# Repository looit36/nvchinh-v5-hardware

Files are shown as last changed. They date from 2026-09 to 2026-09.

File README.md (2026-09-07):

# MiniChinh - Micromouse Robot Controller Board

Dự án thiết kế mạch điều khiển robot dò mê cung (Micromouse) sử dụng phần mềm **KiCad**. Mạch tích hợp vi điều khiển STM32F411 tốc độ cao, driver động cơ kép, cảm biến quán tính IMU 6 trục, cảm biến encoder từ tính và dàn cảm biến quang hồng ngoại (IR).

---

## Hình ảnh Mạch PCB (3D & 2D Layout)

### Phối cảnh 3D
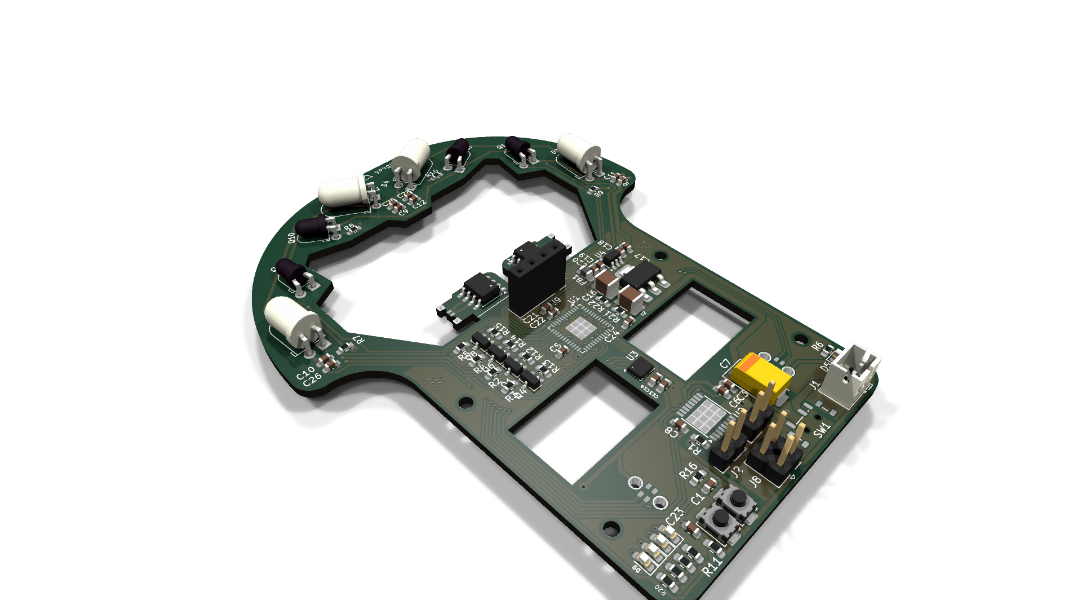
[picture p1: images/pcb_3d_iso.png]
PCB 3D Isometric


| Mặt trên | Mặt dưới |
| :---: | :---: |
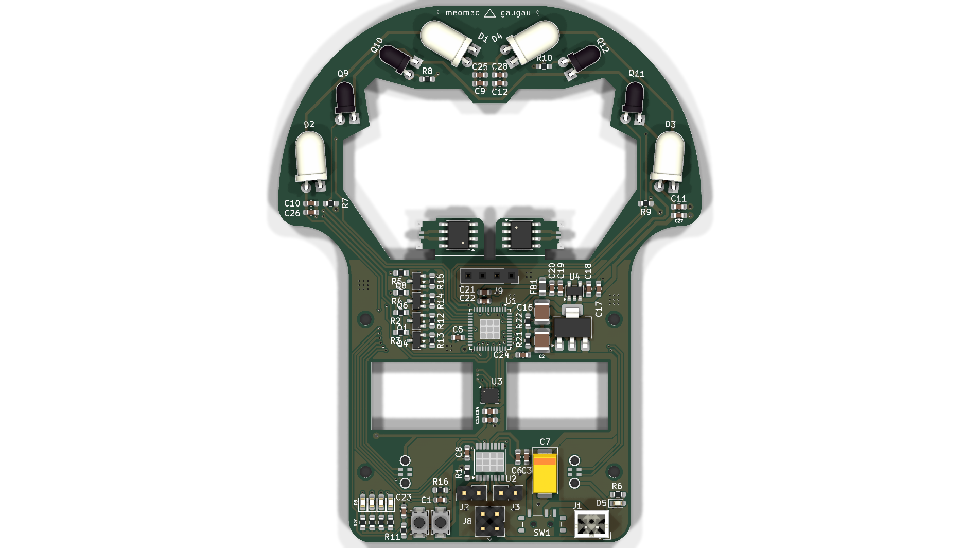
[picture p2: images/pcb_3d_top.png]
PCB Top 3D
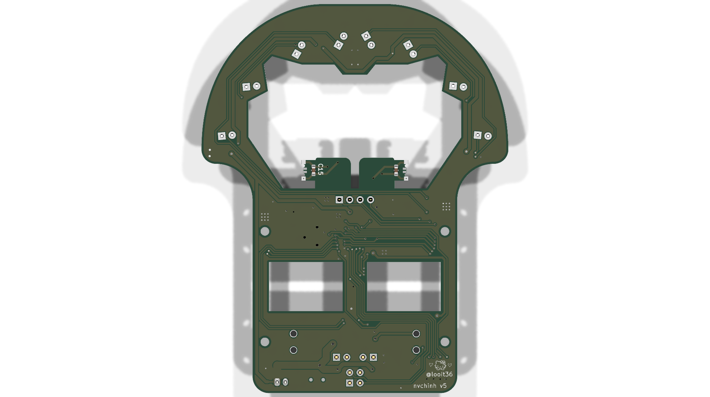
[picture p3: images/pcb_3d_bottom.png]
PCB Bottom 3D
|  |  |

| F.Cu + Silk | B.Cu + Silk |
| :---: | :---: |
| Layout Mặt trước (F.Cu + Silk) | Layout Mặt sau (B.Cu + Silk) |

---

## Sơ đồ Nguyên lý

### 1. Sơ đồ khối chính
Main Schematic

### 2. Sơ đồ mạch phát & thu hồng ngoại
IR Emitter Schematic

---

## Thông số Kỹ thuật Phần cứng

| Thành phần | Chi tiết linh kiện | Chức năng |
| :--- | :--- | :--- |
| **Vi điều khiển (MCU)** | STM32F411CEU6 (UFQFPN-48) | ARM Cortex-M4 100MHz, 512KB Flash, 128KB SRAM |
| **Driver Động cơ** | TI DRV8833PW (HTSSOP-16) | Điều khiển 2 động cơ DC độc lập, dòng tối đa 1.5A/kênh |
| **Cảm biến góc (IMU)** | Bosch BMI160 (LGA-14) | Cảm biến gia tốc & con quay hồi chuyển 6 trục (SPI/I2C) |
| **Bộ mã hóa bánh xe (Encoder)** | 2x MT6701CT (SO-8) | Cảm biến góc từ tính độ chính xác cao cho 2 bánh xe |
| **Cảm biến khoảng cách / Mê cung** | 4x SFH4546 (IR LED) + 4x SFH300 (Phototransistor) | Đo khoảng cách các vách tường mê cung, lái bằng MOSFET AO3400A |
| **Mạch nguồn (Power)** | AMS1117-5.0 & TI TPS73633DBV | Ổn áp 5V và 3.3V Low-Dropout cấp nguồn ổn định cho MCU và cảm biến |
| **Giao tiếp lập trình** | Cổng SWD chuẩn (GND, 3V3, SWDIO, SWCLK) | Nạp và gỡ lỗi bằng ST-Link / J-Link |
| **Ngoại vi & UI** | 5x LED báo trạng thái SMD 0603, 2x nút nhấn, 1x công tắc nguồn MSK12C02 | Giao diện tương tác và chọn chế độ chạy |

---

## Cấu trúc Thư mục

```text
minichinh/
├── minichinh.kicad_pro       # File dự án KiCad chính
├── minichinh.kicad_sch       # Sơ đồ nguyên lý chính
├── iremitter.kicad_sch       # Sơ đồ nguyên lý khối IR Emitter
├── minichinh.kicad_pcb       # Bản vẽ thiết kế mạch in PCB
├── fp-lib-table              # Bảng thư viện footprint
├── mouse.pretty/             # Thư viện footprint tùy chỉnh cho robot
├── minichinh.csv             # Danh sách bảng linh kiện (BOM)
├── geber/                    # Bộ file Gerber sẵn sàng để đặt mạch gia công
├── images/                   # Hình ảnh sơ đồ schematic và render 3D / 2D PCB
│   ├── minichinh.svg
│   ├── minichinh_ir_emitter.svg
│   ├── minichinh_schematic.pdf
│   ├── pcb_3d_top.png
│   ├── pcb_3d_bottom.png
│   ├── pcb_3d_iso.png
│   ├── pcb_top_layout.svg
│   └── pcb_bottom_layout.svg
└── README.md                 # Tài liệu giới thiệu dự án
```

---

## Hướng dẫn Sử dụng

1. **Mở dự án:**
   - Cài đặt KiCad phiên bản 8.0 hoặc 9.0 trở lên.
   - Mở file `minichinh.kicad_pro` để truy cập sơ đồ nguyên lý và layout PCB.
2. **Gia công mạch (PCB Manufacturing):**
   - Bộ file Gerber nén và đầy đủ các lớp đã được tạo sẵn trong thư mục [`geber/`](geber/). Có thể gửi trực tiếp cho các nhà sản xuất PCB (JLCPCB, PCBWay, v.v.).

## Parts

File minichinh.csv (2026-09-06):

Reference | Qty | Value | DNP | Exclude from BOM | Exclude from Board | Footprint | Datasheet
C1,C21,C22,C23 | 4 | 0.1u |  |  |  | Capacitor_SMD:C_0603_1608Metric | ~
C2,C16 | 2 | 100u |  |  |  | Capacitor_SMD:C_1210_3225Metric_Pad1.33x2.70mm_HandSolder | ~
C3,C4,C13,C14,C15,C17,C18,C20,C24,C25,C26,C27,C28 | 13 | 0.1u |  |  |  | Capacitor_SMD:C_0603_1608Metric_Pad1.08x0.95mm_HandSolder | ~
C5 | 1 | 10u |  |  |  | Capacitor_SMD:C_0603_1608Metric | ~
C6 | 1 | 0.01u |  |  |  | Capacitor_SMD:C_0603_1608Metric_Pad1.08x0.95mm_HandSolder | ~
C7 | 1 | 220u |  |  |  | Capacitor_Tantalum_SMD:CP_EIA-7343-31_Kemet-D_HandSolder | ~
C8 | 1 | 2.2u |  |  |  | Capacitor_SMD:C_0603_1608Metric_Pad1.08x0.95mm_HandSolder | ~
C9,C10,C11,C12 | 4 | 4.7u |  |  |  | Capacitor_SMD:C_0603_1608Metric_Pad1.08x0.95mm_HandSolder | ~
C19 | 1 | 10u |  |  |  | Capacitor_SMD:C_0603_1608Metric_Pad1.08x0.95mm_HandSolder | ~
D1,D2,D3,D4 | 4 | SFH4546 |  | Excluded from BOM |  | LED_THT:LED_D5.0mm_Horizontal_O1.27mm_Z3.0mm_Clear | http://www.osram-os.com/Graphics/XPic1/00101982_0.pdf
D5,D6,D7,D8,D9 | 5 | LED |  |  |  | LED_SMD:LED_0603_1608Metric_Pad1.05x0.95mm_HandSolder | ~
FB1 | 1 | FerriteBead |  |  |  | Inductor_SMD:L_0805_2012Metric_Pad1.05x1.20mm_HandSolder | ~
J1 | 1 | Conn_01x02 |  | Excluded from BOM |  | Connector_JST:JST_PH_B2B-PH-K_1x02_P2.00mm_Vertical | ~
J2,J3 | 2 | Conn_01x02 |  | Excluded from BOM |  | Connector_PinHeader_2.54mm:PinHeader_1x02_P2.54mm_Vertical | ~
J4,J7 | 2 | Conn_01x06_Socket |  | Excluded from BOM |  | mouse:STAND_HOST_06 | ~
J5,J6 | 2 | Conn_01x06_Pin |  | Excluded from BOM |  | mouse:STAND_SLAVE_06 | ~
J8 | 1 | Conn_01x04_Pin |  | Excluded from BOM |  | Connector_PinHeader_2.54mm:PinHeader_2x02_P2.54mm_Vertical | ~
J9 | 1 | Conn_01x04_Pin |  | Excluded from BOM |  | Connector_PinSocket_2.54mm:PinSocket_1x04_P2.54mm_Vertical | ~
NT1 | 1 | NetTie_2 |  | Excluded from BOM |  | NetTie:NetTie-2_SMD_Pad0.5mm | ~
NT2 | 1 | NetTie_2 |  | Excluded from BOM |  | NetTie:NetTie-2_SMD_Pad2.0mm | ~
Q1,Q4,Q6,Q8 | 4 | AO3400A |  | Excluded from BOM |  | Package_TO_SOT_SMD:SOT-23 | http://www.aosmd.com/pdfs/datasheet/AO3400A.pdf
Q9,Q10,Q11,Q12 | 4 | SFH300 |  | Excluded from BOM |  | LED_THT:LED_D3.0mm_Horizontal_O1.27mm_Z2.0mm_IRBlack | http://www.osram-os.com/Graphics/XPic2/00101785_0.pdf
R1,R11,R12,R13,R14,R15,R21,R22 | 8 | 47k |  |  |  | Resistor_SMD:R_0603_1608Metric_Pad0.98x0.95mm_HandSolder | ~
R2,R3,R4,R5 | 4 | 10 |  |  |  | Resistor_SMD:R_0603_1608Metric_Pad0.98x0.95mm_HandSolder | ~
R6,R7,R8,R9,R10,R17,R18,R19,R20 | 9 | 1k |  |  |  | Resistor_SMD:R_0603_1608Metric_Pad0.98x0.95mm_HandSolder | ~
R16 | 1 | 10k |  |  |  | Resistor_SMD:R_0603_1608Metric_Pad0.98x0.95mm_HandSolder | ~
SW1 | 1 | SW_DPDT_x2 |  |  |  | Button_Switch_SMD:SW_SPDT_Shouhan_MSK12C02 | ~
SW2,SW3 | 2 | SW_Push |  |  |  | Button_Switch_SMD:SW_SPST_TS-1088-xR025 | ~
U1 | 1 | STM32F411CEUx |  | Excluded from BOM |  | Package_DFN_QFN:QFN-48-1EP_7x7mm_P0.5mm_EP3.5x3.5mm | https://www.st.com/resource/en/datasheet/stm32f411ce.pdf
U2 | 1 | DRV8833PW |  |  |  | Package_SO:HTSSOP-16-1EP_4.4x5mm_P0.65mm_EP3.4x5mm | http://www.ti.com/lit/ds/symlink/drv8833.pdf
U3 | 1 | BMI160 |  | Excluded from BOM |  | Package_LGA:Bosch_LGA-14_3x2.5mm_P0.5mm | https://www.bosch-sensortec.com/media/boschsensortec/downloads/datasheets/bst-bmi160-ds000.pdf
U4 | 1 | TPS73633DBV |  |  |  | Package_TO_SOT_SMD:SOT-23-5 | http://www.ti.com/lit/ds/symlink/tps736.pdf
U5 | 1 | AMS1117-5.0 |  |  |  | Package_TO_SOT_SMD:SOT-223-3_TabPin2 | http://www.advanced-monolithic.com/pdf/ds1117.pdf
U6,U7 | 2 | MT6701CT |  | Excluded from BOM |  | Package_SO:SO-8_3.9x4.9mm_P1.27mm | https://www.magntek.com.cn/upload/MT6701_Rev.1.5.pdf

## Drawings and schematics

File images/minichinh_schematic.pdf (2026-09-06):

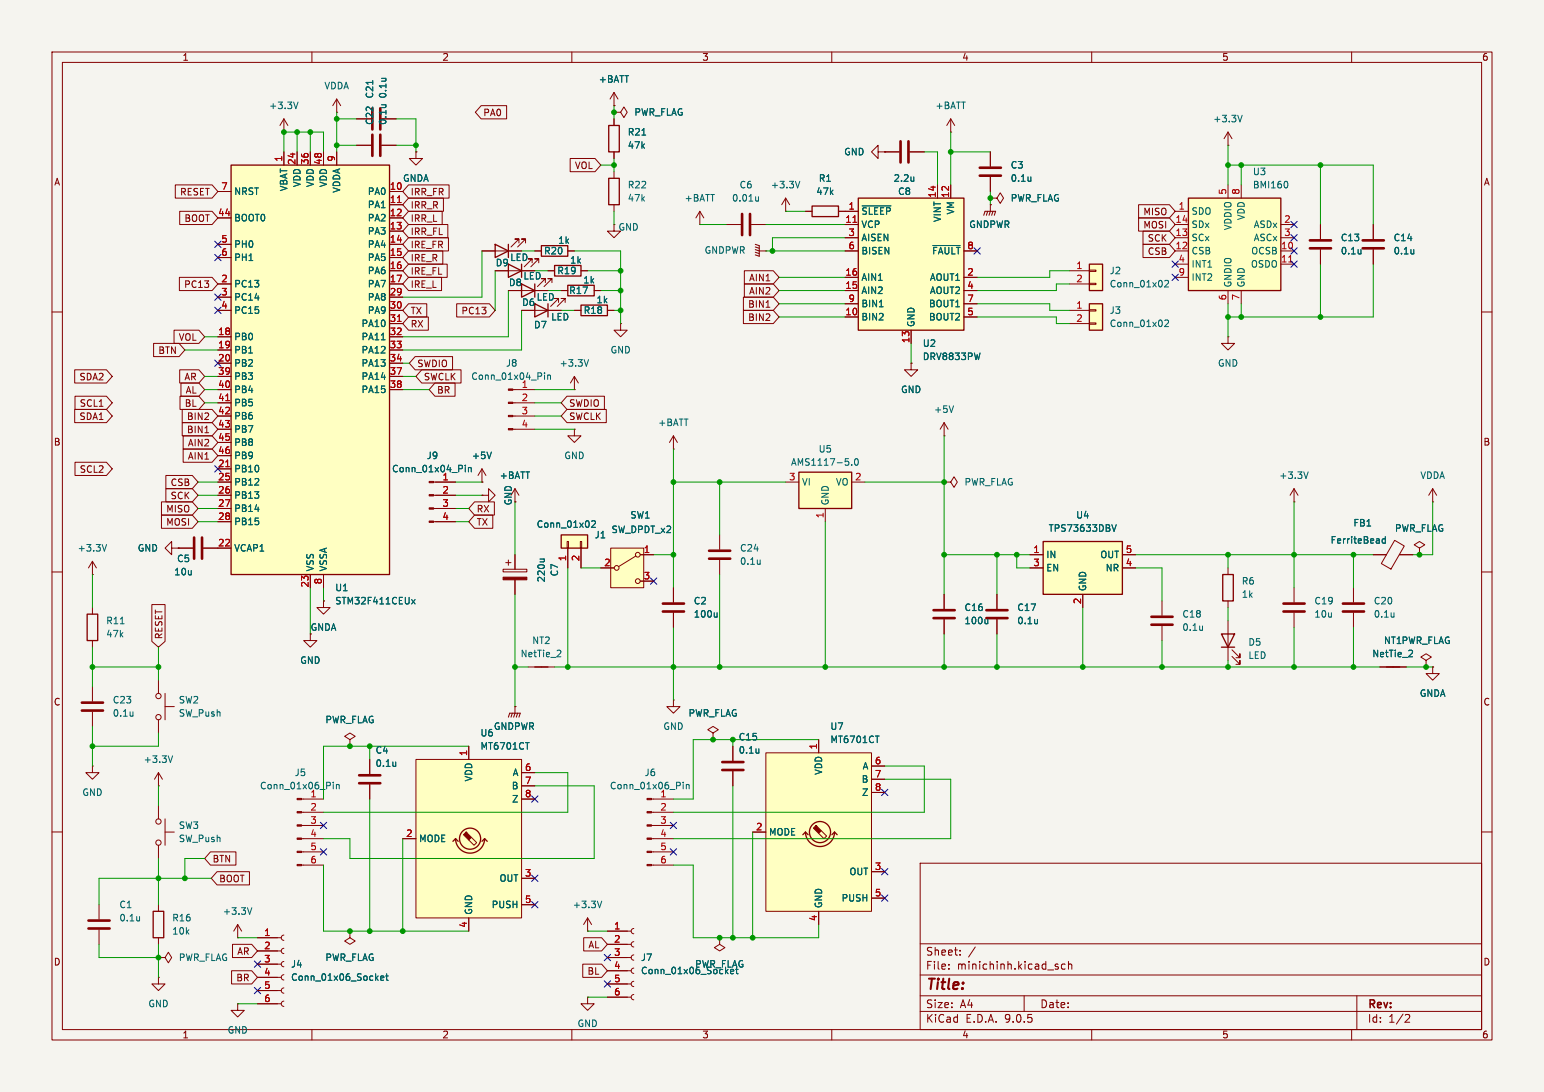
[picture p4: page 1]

1 VDD 24 VDD 36 VSS 23 VDD 48 VSSA
BLBIN2 AL MOSIBOOT
SCK MOSI CSB MISO

7 ASDx 2 ASCx 3 OCSB 10 OSDO 11 U3BMI160 C2

Id: 1/2 Title: File: minichinh.kicad_sch Sheet: /

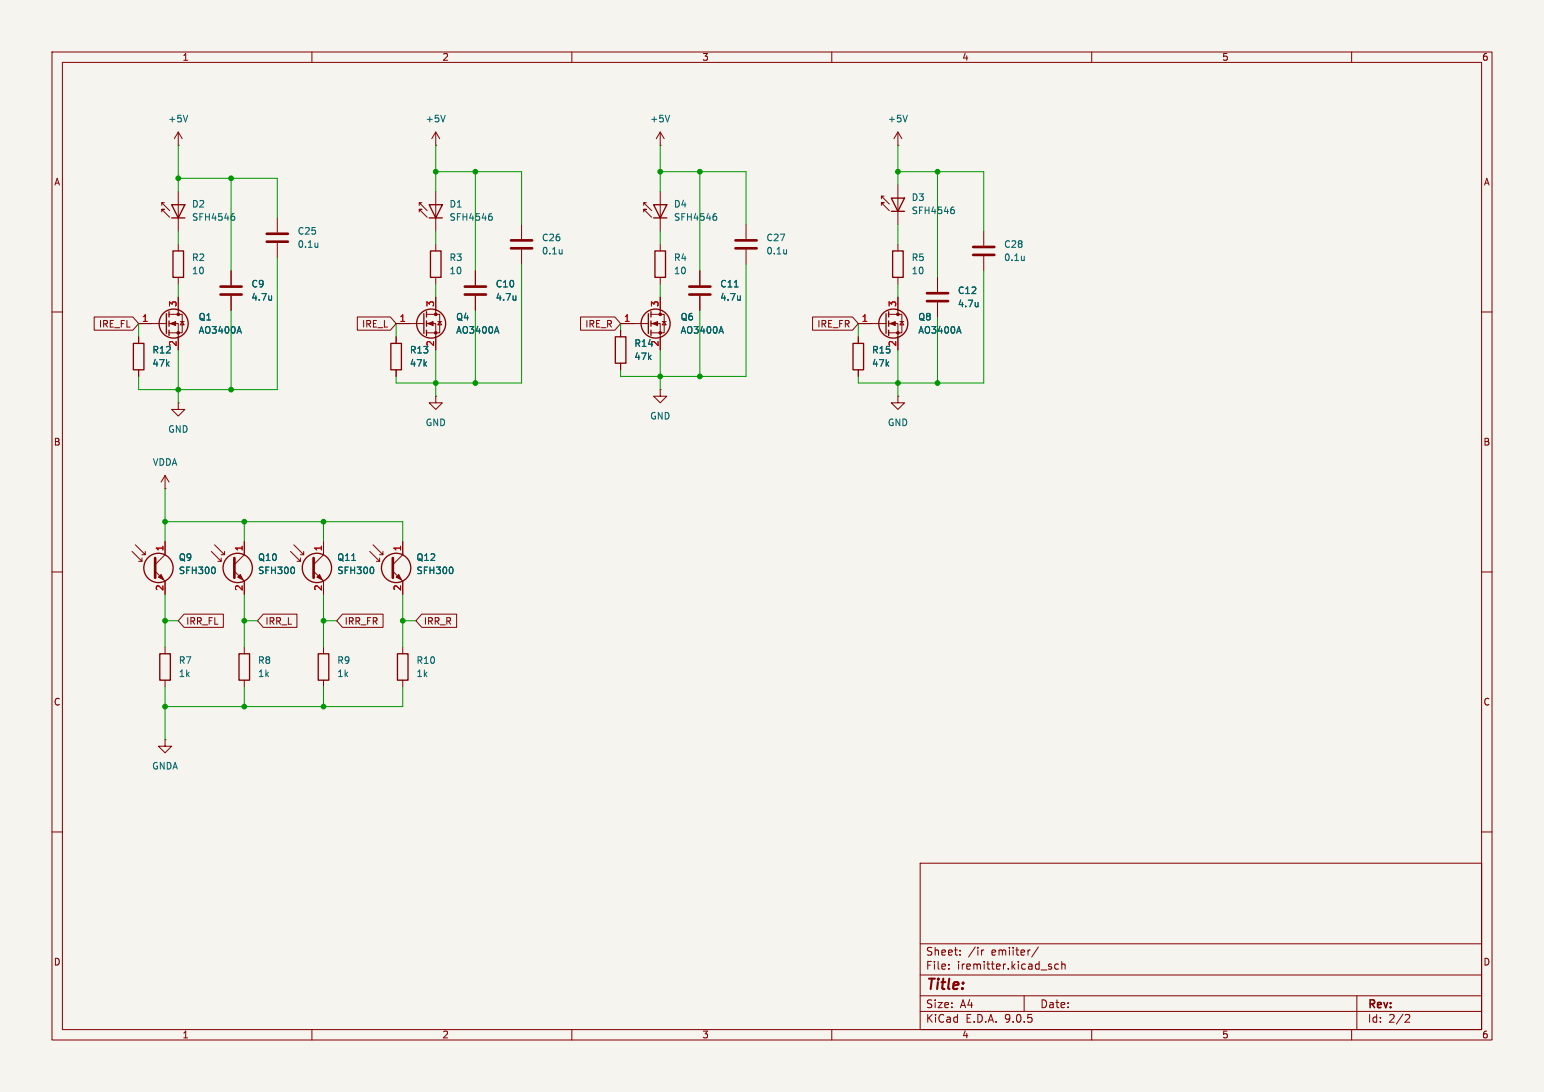
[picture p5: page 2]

Id: 2/2 Title: File: iremitter.kicad_sch Sheet: /ir emiiter/ R10

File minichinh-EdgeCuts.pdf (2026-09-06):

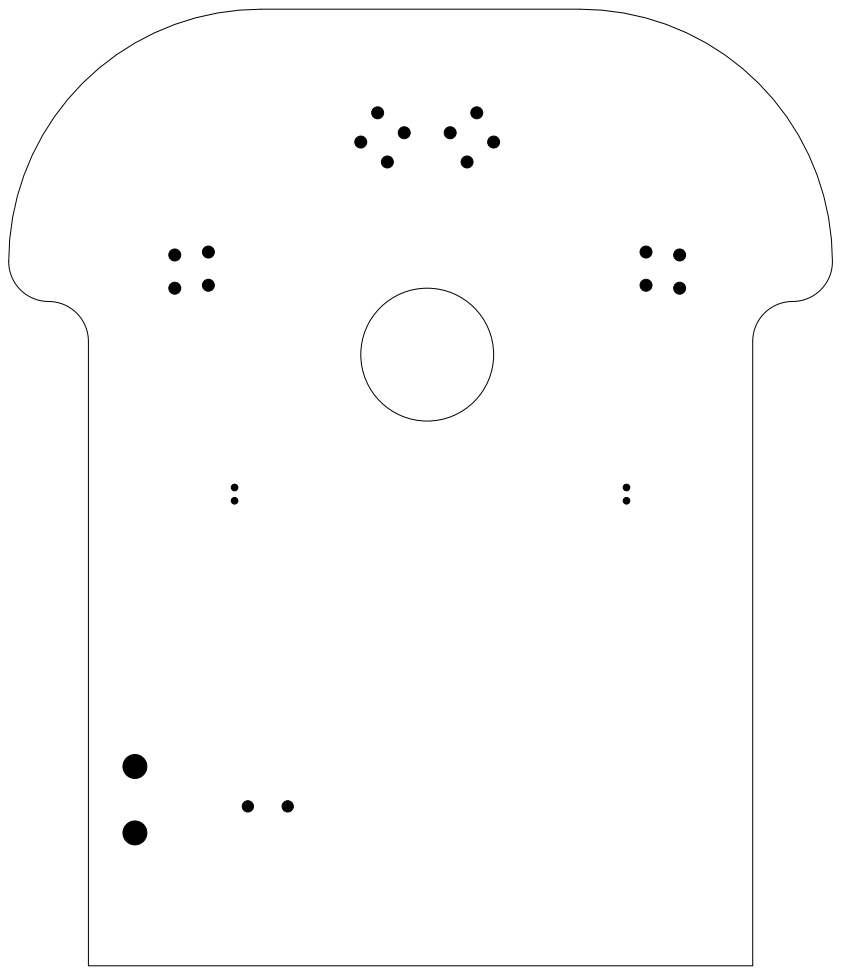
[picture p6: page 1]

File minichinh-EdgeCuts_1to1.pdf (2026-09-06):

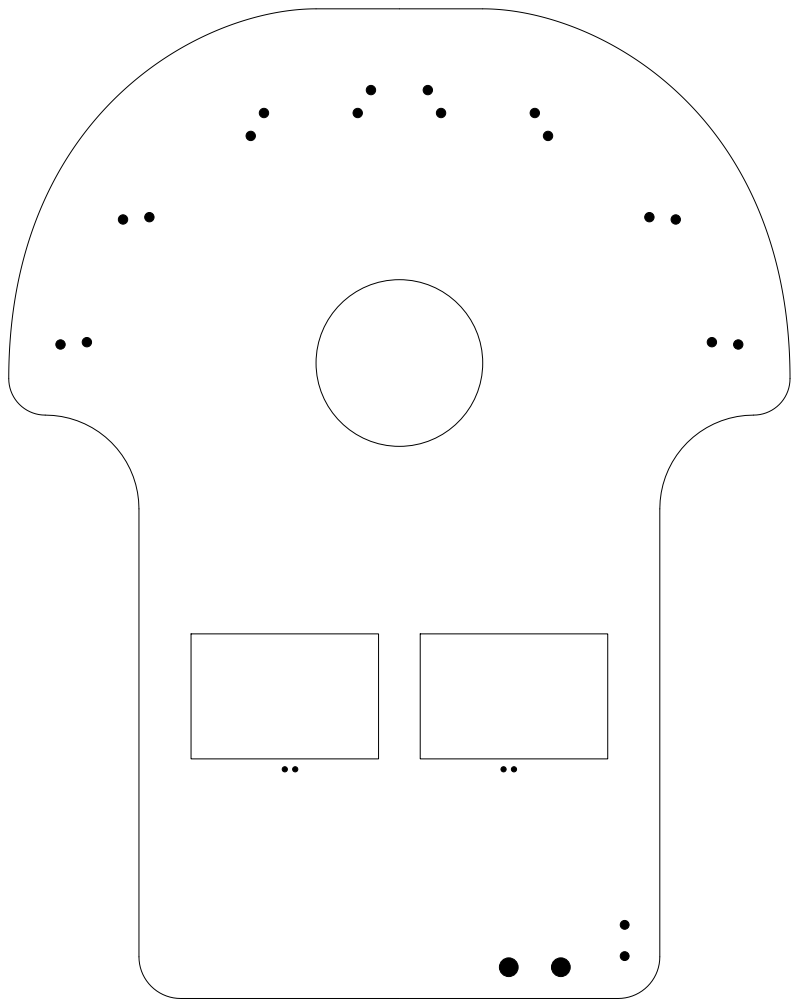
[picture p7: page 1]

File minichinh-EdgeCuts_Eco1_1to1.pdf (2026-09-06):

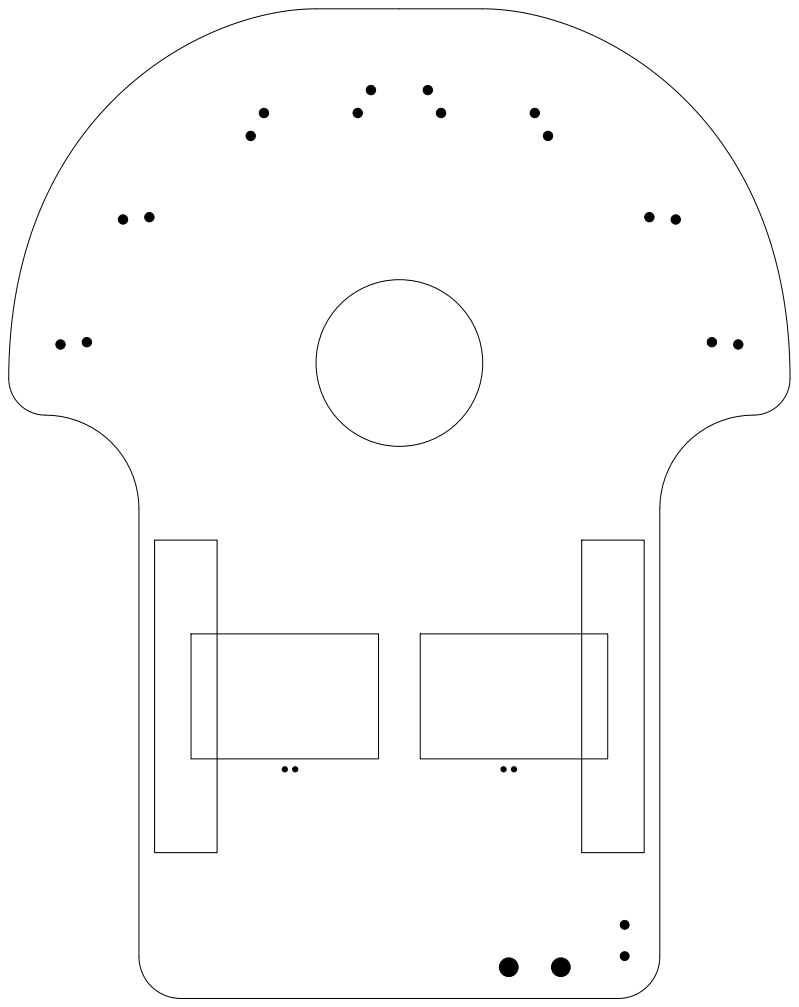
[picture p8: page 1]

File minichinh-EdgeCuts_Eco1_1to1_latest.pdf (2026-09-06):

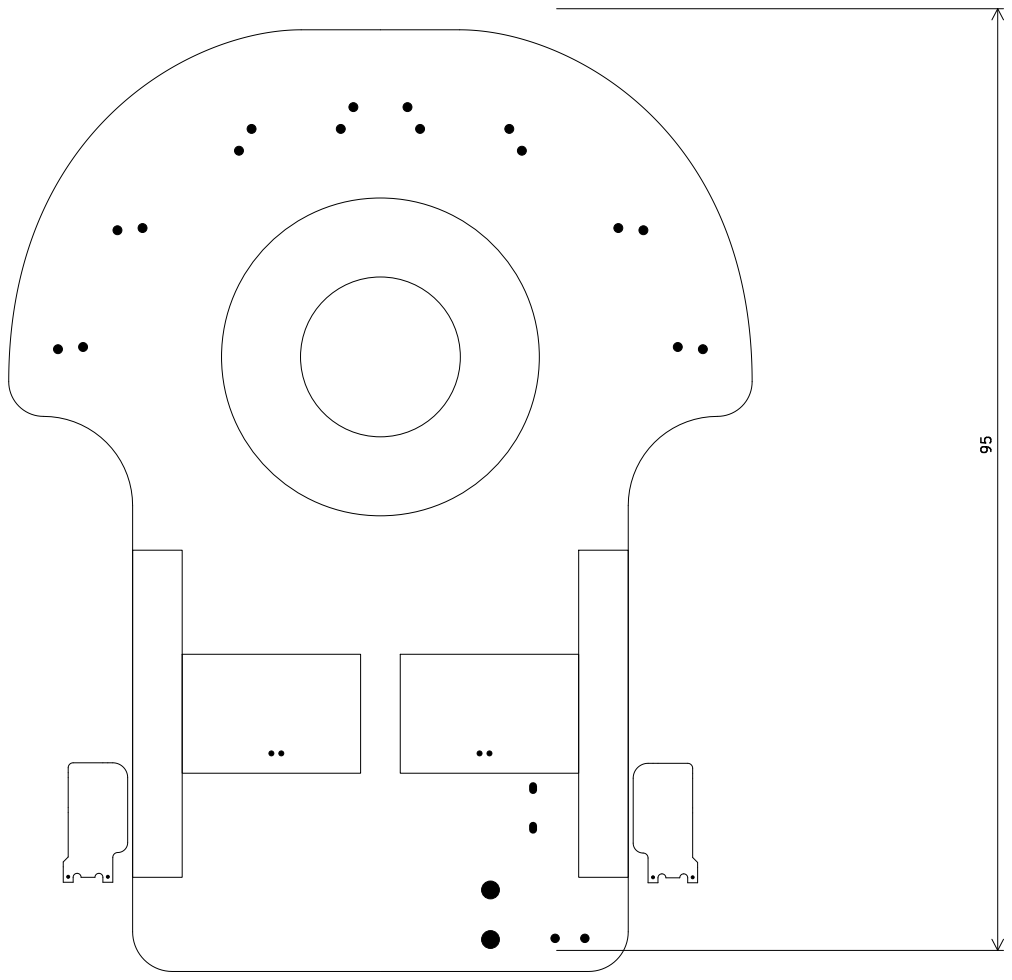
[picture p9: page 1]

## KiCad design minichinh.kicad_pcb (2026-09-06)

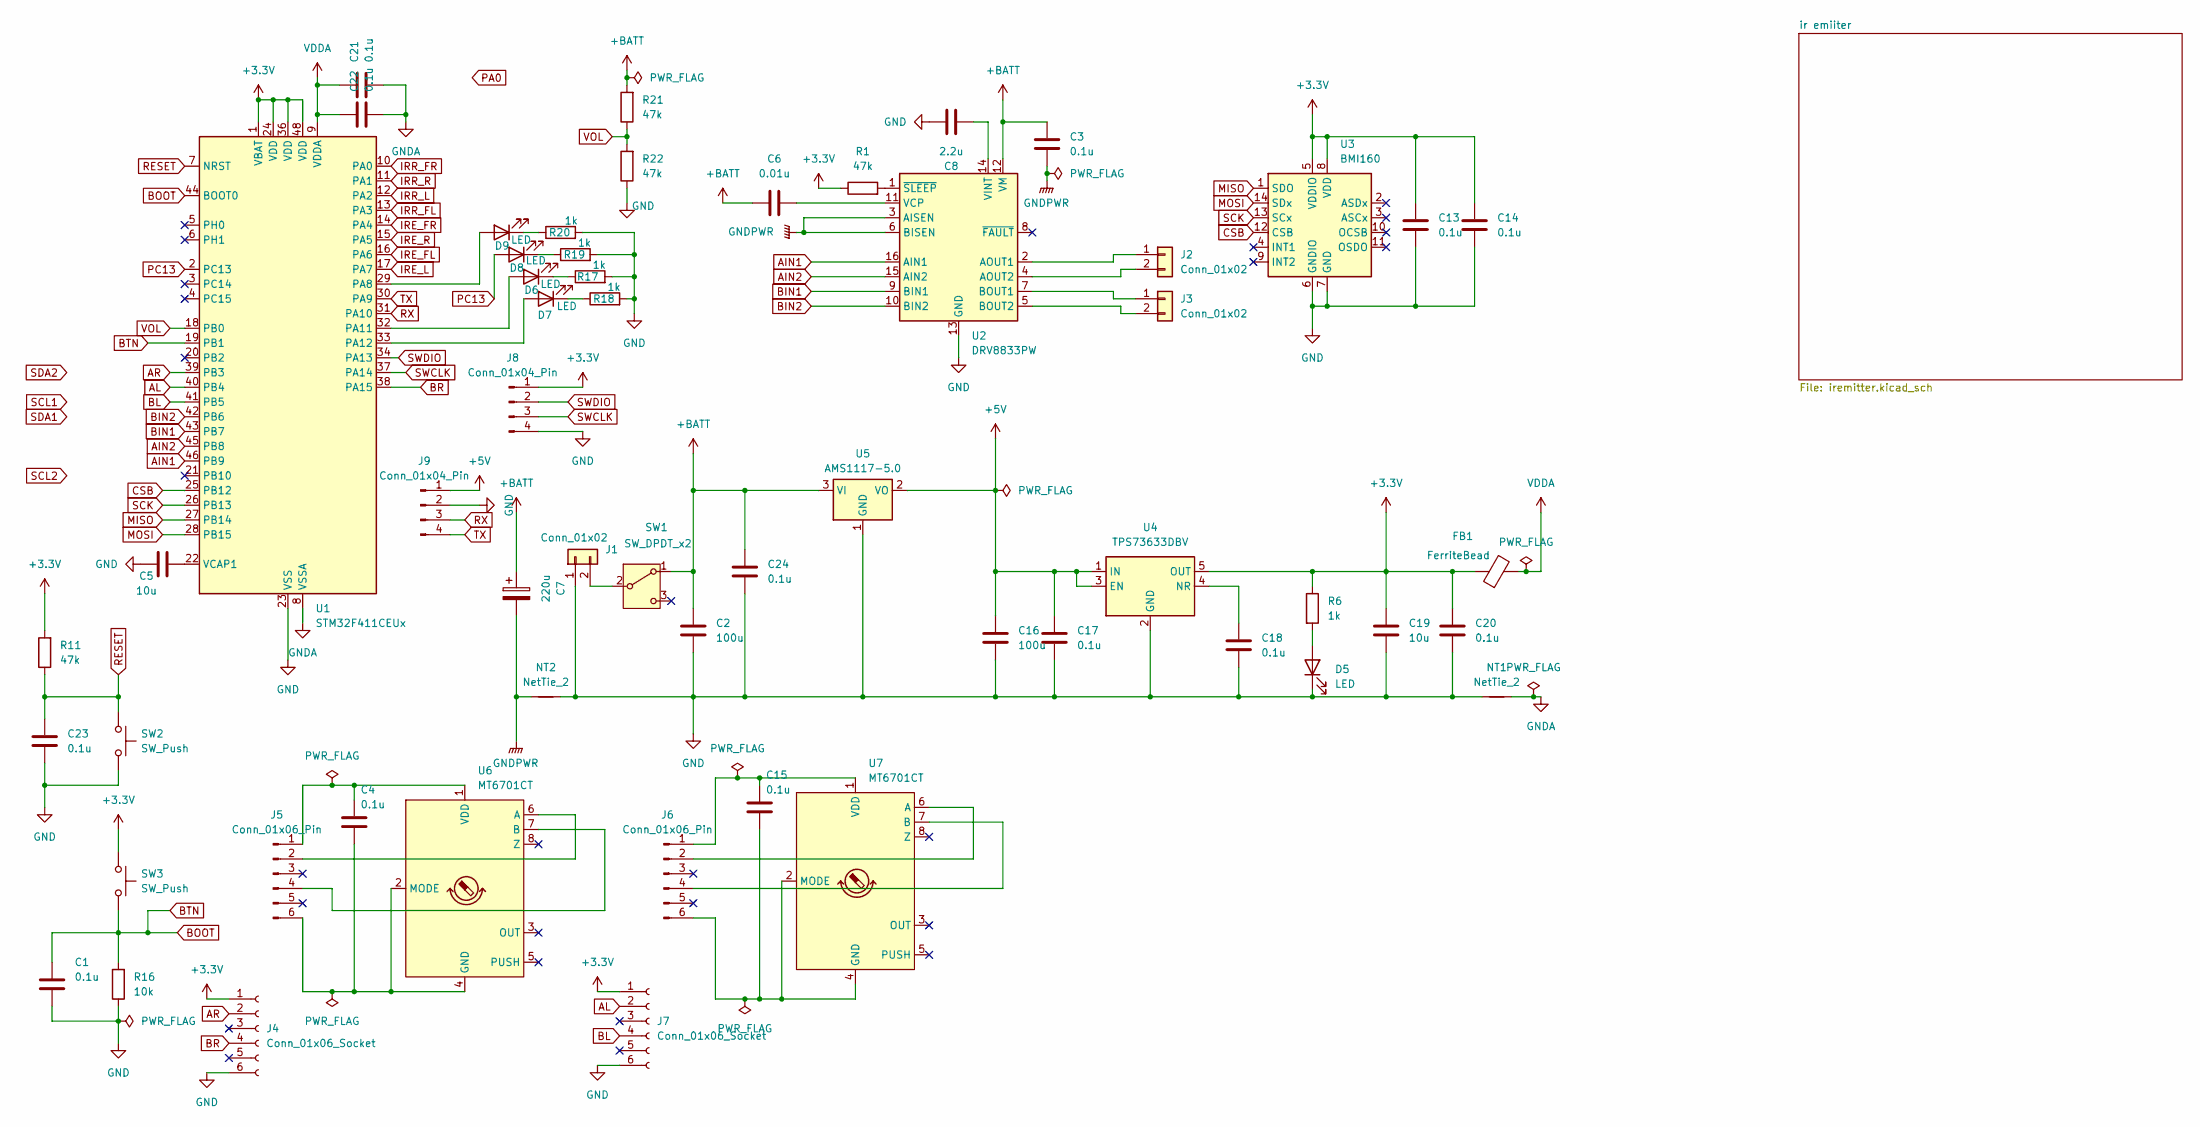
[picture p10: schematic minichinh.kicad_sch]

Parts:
C1, C21, C22, C23: 0.1u; C_0603_1608Metric
C2, C16: 100u; C_1210_3225Metric_Pad1.33x2.70mm_HandSolder
C3, C4, C13, C14, C15, C17, C18, C20, C24: 0.1u; C_0603_1608Metric_Pad1.08x0.95mm_HandSolder
C5: 10u; C_0603_1608Metric
C6: 0.01u; C_0603_1608Metric_Pad1.08x0.95mm_HandSolder
C7: 220u; CP_EIA-7343-31_Kemet-D_HandSolder
C8: 2.2u; C_0603_1608Metric_Pad1.08x0.95mm_HandSolder
C19: 10u; C_0603_1608Metric_Pad1.08x0.95mm_HandSolder
D5, D6, D7, D8, D9: LED; LED_0603_1608Metric_Pad1.05x0.95mm_HandSolder
FB1: FerriteBead; L_0805_2012Metric_Pad1.05x1.20mm_HandSolder
J1: Conn_01x02; JST_PH_B2B-PH-K_1x02_P2.00mm_Vertical
J2, J3: Conn_01x02; PinHeader_1x02_P2.54mm_Vertical
J4, J7: Conn_01x06_Socket; STAND_HOST_06
J5, J6: Conn_01x06_Pin; STAND_SLAVE_06
J8: Conn_01x04_Pin; PinHeader_2x02_P2.54mm_Vertical
J9: Conn_01x04_Pin; PinSocket_1x04_P2.54mm_Vertical
NT1: NetTie_2; NetTie-2_SMD_Pad0.5mm
NT2: NetTie_2; NetTie-2_SMD_Pad2.0mm
R1, R11, R21, R22: 47k; R_0603_1608Metric_Pad0.98x0.95mm_HandSolder
R6, R17, R18, R19, R20: 1k; R_0603_1608Metric_Pad0.98x0.95mm_HandSolder
R16: 10k; R_0603_1608Metric_Pad0.98x0.95mm_HandSolder
SW1: SW_DPDT_x2; SW_SPDT_Shouhan_MSK12C02
SW2, SW3: SW_Push; SW_SPST_TS-1088-xR025
U1: STM32F411CEUx; QFN-48-1EP_7x7mm_P0.5mm_EP3.5x3.5mm
U2: DRV8833PW; HTSSOP-16-1EP_4.4x5mm_P0.65mm_EP3.4x5mm
U3: BMI160; Bosch_LGA-14_3x2.5mm_P0.5mm
U4: TPS73633DBV; SOT-23-5
U5: AMS1117-5.0; SOT-223-3_TabPin2
U6, U7: MT6701CT; SO-8_3.9x4.9mm_P1.27mm

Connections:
+3.3V: C13.2, C14.2, C19.1, C20.1, FB1.1, J4.1, J7.1, J8.1, R1.1, R6.1, R11.2, SW3.1, U1.1 (VBAT), U1.24 (VDD), U1.36 (VDD), U1.48 (VDD), U3.5 (VDDIO), U3.8 (VDD), U4.5 (OUT)
+5V: C16.1, C17.1, J9.1, U4.1 (IN), U4.3 (EN), U5.2 (VO); also elsewhere on the board
+BATT: C2.1, C3.1, C6.1, C7.1, C24.1, R21.2, SW1.1 (A), U2.12 (VM), U5.3 (VI)
AIN1: U1.46 (PB9), U2.16 (AIN1)
AIN2: U1.45 (PB8), U2.15 (AIN2)
AL: J7.2, U1.40 (PB4)
AR: J4.2, U1.39 (PB3)
BIN1: U1.43 (PB7), U2.9 (BIN1)
BIN2: U1.42 (PB6), U2.10 (BIN2)
BL: J7.4, U1.41 (PB5)
BOOT: C1.1, R16.2, SW3.2, U1.19 (PB1), U1.44 (BOOT0)
BR: J4.4, U1.38 (PA15)
CSB: U1.25 (PB12), U3.12 (CSB)
GND: C1.2, C2.2, C5.1, C8.2, C13.1, C14.1, C16.2, C17.2, C18.2, C19.2, C20.2, C23.2, C24.2, D5.1 (K), J1.1, J4.6, J7.6, J8.4, J9.2, NT1.1, NT2.2, R16.1, R17.2, R18.2, R19.2, R20.2, R22.1, SW2.2, U1.23 (VSS), U1.35 (VSS), U1.47 (VSS), U1.49 (VSS), U2.13 (GND), U3.6 (GNDIO), U3.7 (GND), U4.2 (GND), U5.1 (GND); also elsewhere on the board
GNDA: C21.2, C22.2, NT1.2, U1.8 (VSSA); also elsewhere on the board
GNDPWR: C3.2, C7.2, NT2.1, U2.3 (AISEN), U2.6 (BISEN)
IRE_FL: U1.16 (PA6); also elsewhere on the board
IRE_FR: U1.14 (PA4); also elsewhere on the board
IRE_L: U1.17 (PA7); also elsewhere on the board
IRE_R: U1.15 (PA5); also elsewhere on the board
IRR_FL: U1.13 (PA3); also elsewhere on the board
IRR_FR: U1.10 (PA0); also elsewhere on the board
IRR_L: U1.12 (PA2); also elsewhere on the board
IRR_R: U1.11 (PA1); also elsewhere on the board
MISO: U1.27 (PB14), U3.1 (SDO)
MOSI: U1.28 (PB15), U3.14 (SDx)
unnamed: D5.2 (A), R6.2
unnamed: D6.2 (A), U1.32 (PA11)
unnamed: D6.1 (K), R17.1
unnamed: D7.2 (A), U1.33 (PA12)
unnamed: D7.1 (K), R18.1
unnamed: D8.1 (K), R19.1
unnamed: D9.2 (A), U1.29 (PA8)
unnamed: D9.1 (K), R20.1
unnamed: J1.2, SW1.2 (B)
unnamed: J2.1, U2.2 (AOUT1)
unnamed: J2.2, U2.4 (AOUT2)
unnamed: J3.1, U2.7 (BOUT1)
unnamed: J3.2, U2.5 (BOUT2)
unnamed: C4.1, J5.1, U6.1 (VDD)
unnamed: J5.2, U6.6 (A)
unnamed: J5.4, U6.7 (B)
unnamed: C4.2, J5.6, U6.2 (MODE), U6.4 (GND)
unnamed: C15.1, J6.1, U7.1 (VDD)
unnamed: J6.2, U7.6 (A)
unnamed: J6.4, U7.7 (B)
unnamed: C15.2, J6.6, U7.2 (MODE), U7.4 (GND)
unnamed: C5.2, U1.22 (VCAP1)
unnamed: C6.2, U2.11 (VCP)
unnamed: C8.1, U2.14 (VINT)
unnamed: R1.2, U2.1 (~SLEEP)
unnamed: C18.1, U4.4 (NR)
PC13: D8.2 (A), U1.2 (PC13)
RESET: C23.1, R11.1, SW2.1, U1.7 (NRST)
RX: J9.3, U1.31 (PA10)
SCK: U1.26 (PB13), U3.13 (SCx)
SWCLK: J8.3, U1.37 (PA14)
SWDIO: J8.2, U1.34 (PA13)
TX: J9.4, U1.30 (PA9)
VDDA: C21.1, C22.1, FB1.2, U1.9 (VDDA); also elsewhere on the board
VOL: R21.1, R22.2, U1.18 (PB0)

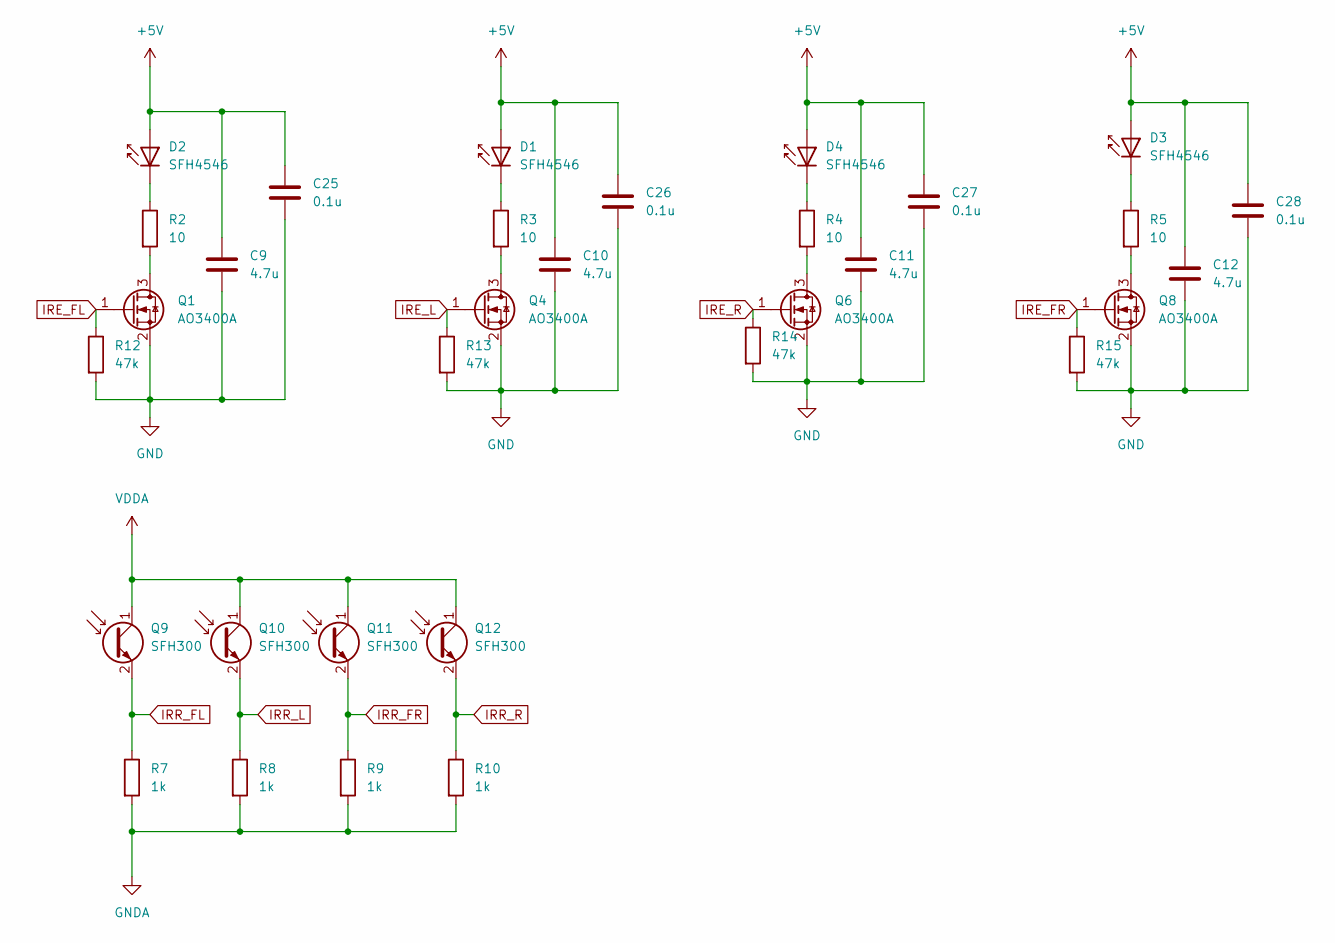
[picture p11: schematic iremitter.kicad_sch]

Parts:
C9, C10, C11, C12: 4.7u; C_0603_1608Metric_Pad1.08x0.95mm_HandSolder
C25, C26, C27, C28: 0.1u; C_0603_1608Metric_Pad1.08x0.95mm_HandSolder
D1, D2, D3, D4: SFH4546; LED_D5.0mm_Horizontal_O1.27mm_Z3.0mm_Clear
Q1, Q4, Q6, Q8: AO3400A; SOT-23
Q9, Q10, Q11, Q12: SFH300; LED_D3.0mm_Horizontal_O1.27mm_Z2.0mm_IRBlack
R2, R3, R4, R5: 10; R_0603_1608Metric_Pad0.98x0.95mm_HandSolder
R7, R8, R9, R10: 1k; R_0603_1608Metric_Pad0.98x0.95mm_HandSolder
R12, R13, R14, R15: 47k; R_0603_1608Metric_Pad0.98x0.95mm_HandSolder

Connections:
+5V: C9.1, C10.1, C11.1, C12.1, C25.1, C26.1, C27.1, C28.1, D1.2 (A), D2.2 (A), D3.2 (A), D4.2 (A); also elsewhere on the board
GND: C9.2, C10.2, C11.2, C12.2, C25.2, C26.2, C27.2, C28.2, Q1.2 (S), Q4.2 (S), Q6.2 (S), Q8.2 (S), R12.2, R13.2, R14.2, R15.2; also elsewhere on the board
GNDA: R7.2, R8.2, R9.2, R10.2; also elsewhere on the board
IRE_FL: Q1.1 (G), R12.1; also elsewhere on the board
IRE_FR: Q8.1 (G), R15.1; also elsewhere on the board
IRE_L: Q4.1 (G), R13.1; also elsewhere on the board
IRE_R: Q6.1 (G), R14.1; also elsewhere on the board
IRR_FL: Q9.2 (E), R7.1; also elsewhere on the board
IRR_FR: Q11.2 (E), R9.1; also elsewhere on the board
IRR_L: Q10.2 (E), R8.1; also elsewhere on the board
IRR_R: Q12.2 (E), R10.1; also elsewhere on the board
unnamed: D1.1 (K), R3.1
unnamed: D2.1 (K), R2.1
unnamed: D3.1 (K), R5.1
unnamed: D4.1 (K), R4.1
unnamed: Q1.3 (D), R2.2
unnamed: Q4.3 (D), R3.2
unnamed: Q6.3 (D), R4.2
unnamed: Q8.3 (D), R5.2
VDDA: Q9.1 (C), Q10.1 (C), Q11.1 (C), Q12.1 (C); also elsewhere on the board

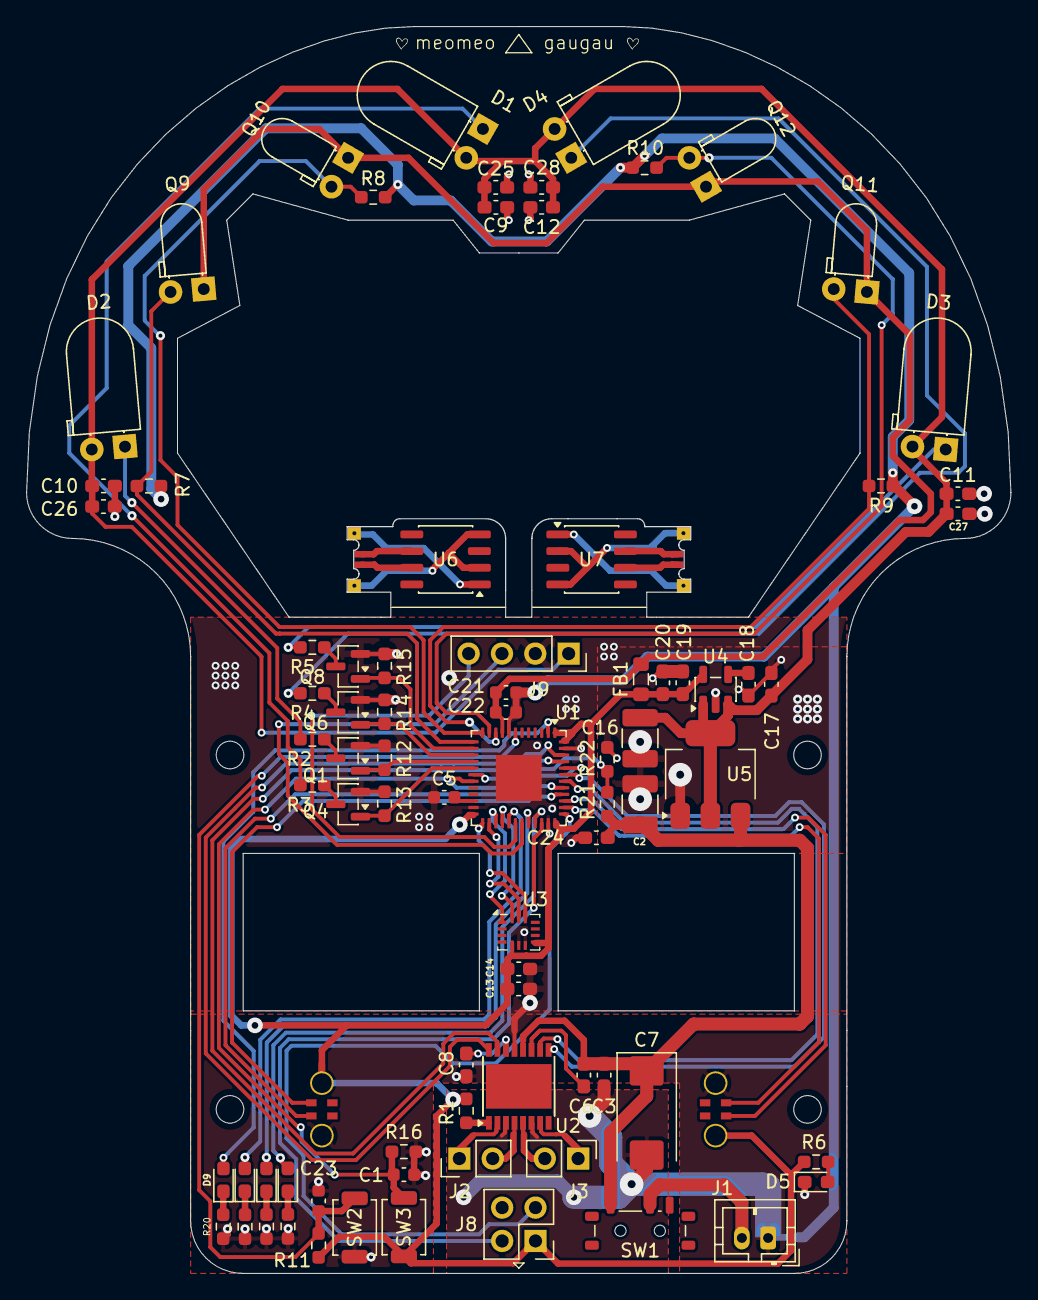
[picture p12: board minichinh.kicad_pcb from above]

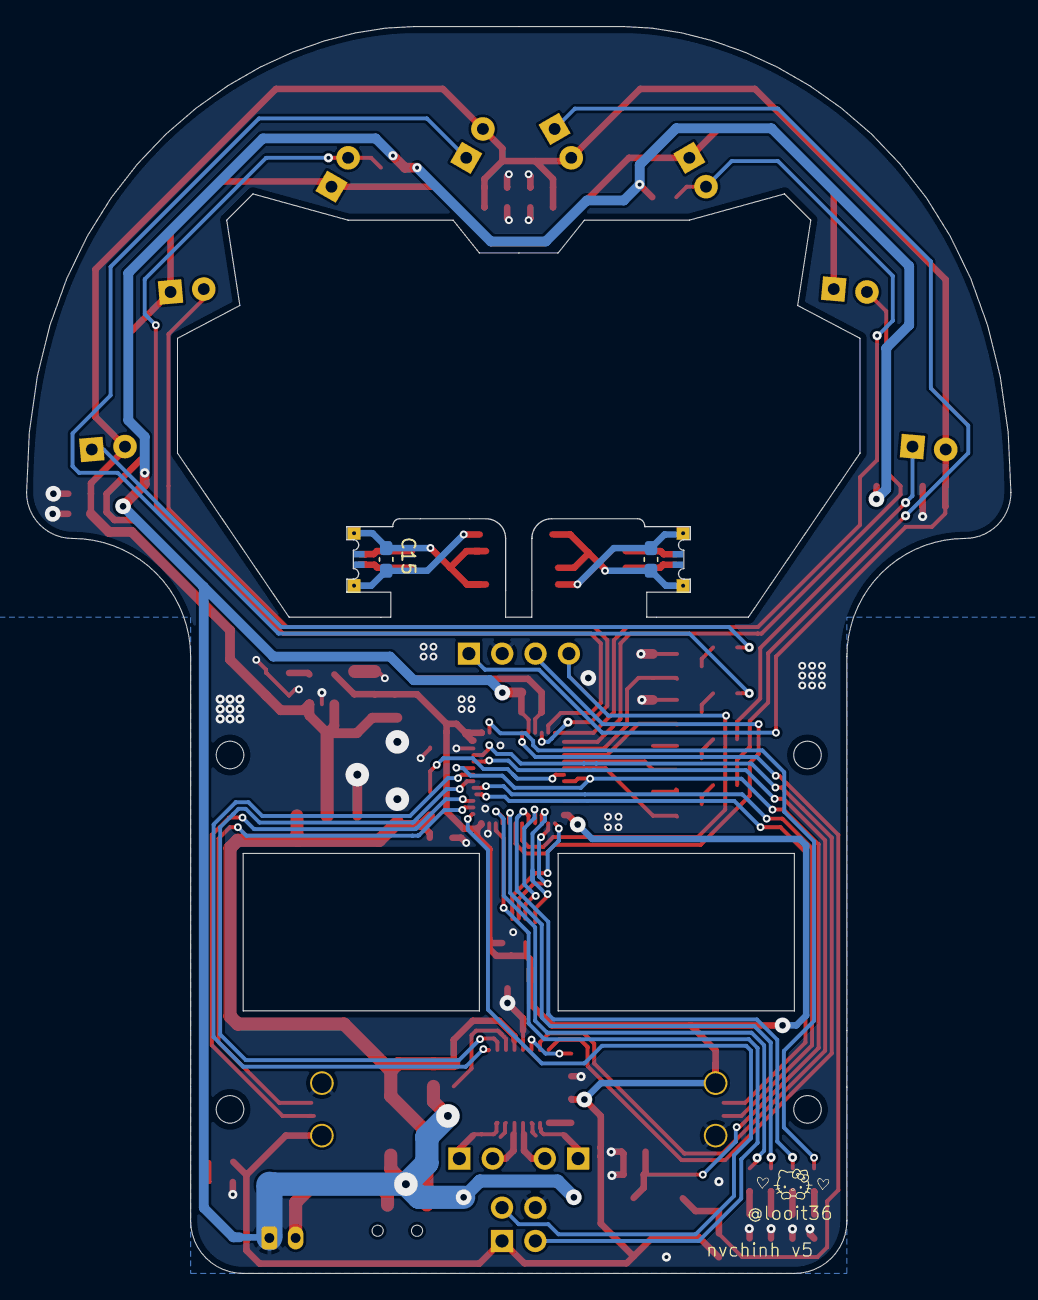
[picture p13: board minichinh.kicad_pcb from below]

Board: 2 copper layers, 75.0 x 95.0 mm, 89 parts (4 on the bottom side), 69 nets.

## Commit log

2026-09-06 Initial commit: KiCad schematic, PCB, Gerber, 3D renders, and README
    [iremitter.kicad_sch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]
2026-09-06 Fix 3D isometric view orientation, crop 2D layouts to board bounds, and remove emojis from README
2026-09-06 Remove schematic description line from README
